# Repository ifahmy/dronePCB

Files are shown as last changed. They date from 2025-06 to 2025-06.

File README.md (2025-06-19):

# Tiny Drone Flight Controller PCB

This repository documents the design of a custom STM32-based nano drone flight controller, incorporating power management, 2.4 GHz radio, motion sensors, and brushed motor drivers. Designed for compatibility with **ArduPilot** and **Betaflight**.

---

## Microcontroller Unit (MCU)

- **STM32F722RET6**, selected for performance and documentation.
- 8 MHz HSE oscillator with tuning capacitors for STM32 and sensors.
- Power monitoring via voltage divider and ADC.
- On-board **SWDIO/SWCLK** for debugging and bootloader flashing (DFU mode via BOOT and RESET).
- **Decoupling capacitors** used throughout for stability under current spikes.

---

## MCU Pin Assignments

- Verified via STM32CubeIDE.
- PWM signals generated via hardware timers.
- Deconflicted JTAG and other peripheral capabilities.
- SPI used for IMU (vs I2C in Nano).
- Pin selections support both ArduPilot and Betaflight configurations.

---

## Sensors & Motor Drivers

- **IMU**: ICM-42688-P (connected via SPI3 for efficiency).
- **Barometer**: MS5611 (lower data rate, connected via I2C with pull-ups).
- **Motors**: Driven by SI2302 N-Channel MOSFETs (supports high-frequency PWM, no gate driver required).
- **Flyback protection**: SS14 Schottky diodes.
- **Gate protection**: 10Ω resistors to suppress transients.

---

## Power Regulation & Charging

- **Battery input** with reverse polarity protection.
- **MCP73831-2** for LiPo charging via USB (charge current ~40 mA with 24.9k resistor).
- **MCP1700** LDO regulator (2.8V output) for analog and digital circuits.
- **Ideal diode configuration** using PMOS + Schottky for automatic switching between USB and battery.

---

## 2.4 GHz Radio & USB Interface

- **nRF24L01+** radio connected to SPI1 with CE and CS via GPIO.
- External ¼-wave wire antenna (~1.25”) with matching network based on datasheet.
- **16 MHz oscillator** for the radio.
- **Micro-USB** interface with 27Ω series resistors.
- **PRTR5V0U2X** for USB ESD protection.

---

## PCB Design Overview

- 4-layer board:
  - Top and Bottom: Signal layers
  - Inner Layers: +2.8V and Ground
- Motor PWM routed in +2.8V layer due to limited space.

---

## Next Steps & Recommendations

- Order fabricated PCBs.
- Flash bootloader / firmware using DFU for Betaflight/ArduPilot.

### Future Improvements
- Migrate from 4-layer to 2-layer for cost/manufacturing optimization.
- Reroute motor gate PWM signals away from power planes if space allows.

---

## Bill of Materials (BOM)

For a full list, see the Bill of Materials Excel sheet. Sample entries:

| Ref | Description | Value | Manufacturer Part # | Digi-Key Part # |
|-----|---|---|---|---|
| U1  | IMU | ICM-42688-P | ICM-42688-P | 1428-ICM-42688-PTR-ND |
| U2  | Barometer | MS5611-01BA | MS561101BA03-50 | 223-1622-1-ND |
| U3  | RF Radio | nRF24L01+ | NRF24L01P-T | 4823-NRF24L01P-T-ND |

---

## Tools Used

- STM32CubeIDE (Pin config, firmware)
- KiCad 9.0  (PCB layout and schematic)
- DigiKey (Component sourcing)
- Calipers (Nano board dimensions)

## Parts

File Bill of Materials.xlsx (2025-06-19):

Item # | Reference | Qty | Description | Value | Footprint | Manufacturer PN | Digikey PN
1 | SW1 | 1 | SWITCH SLIDE SPDT 100MA 6V | SW_SPDT | Button_Switch_SMD:Nidec_Copal_CAS-120A | CAS-120A | CAS-120A-ND
2 | C9 | 1 | CAP CER 1000PF 25V X7R 0201 | 1n | Capacitor_SMD:C_0201_0603Metric | GRM033R71E102KA01D | 490-3184-1-ND
3 | C10,C12 | 2 | CAP CER 10000PF 25V X5R 0201 | 10n | Capacitor_SMD:C_0201_0603Metric | GRM033R61E103KA12D | 490-7194-1-ND
4 | C13,C39,C40,C41,C42,C45,C46 | 7 | CAP CER 0.1UF 6.3V X5R 0201 | 100n | Capacitor_SMD:C_0201_0603Metric | CL03A104KQ3NNNC | 1276-1013-1-ND
5 | C1,C2,C37 | 3 | CAP CER 4.7UF 6.3V X5R 0402 | 4.7u | Capacitor_SMD:C_0402_1005Metric | JMK105BBJ475MV-F | 587-2787-1-ND
6 | C3 | 1 | AP CER 1PF 50V C0G/NP0 0402 | 1p | Capacitor_SMD:C_0402_1005Metric | GJM1555C1H1R0BB01D | 490-6073-1-ND
7 | C4,C43 | 2 | CAP CER 0.1UF 10V X7R 0402 | 0.1u | Capacitor_SMD:C_0402_1005Metric | CL05B104KP5NNNC | 1276-1002-1-ND
8 | C5 | 1 | CAP CER 1.5PF 50V C0G/NP0 0402 | 1.5p | Capacitor_SMD:C_0402_1005Metric | 0402N1R5B500CT | 1292-1274-1-ND
9 | C6 | 1 | CAP CER 2200PF 50V X7R 0402 | 2.2n | Capacitor_SMD:C_0402_1005Metric | C0402C222J5RACTU | 399-C0402C222J5RACTUCT-ND
10 | C8 | 1 | CAP CER 4.7PF 50V C0G/NP0 0402 | 4.7p | Capacitor_SMD:C_0402_1005Metric | GRM1555C1H4R7CA01D | 490-5874-1-ND
11 | C11 | 1 | CAP CER 0.033UF 16V X7R 0402 | 33n | Capacitor_SMD:C_0402_1005Metric | GRM155R71C333KA01D | 490-3257-1-ND
12 | C14,C16 | 2 | CAP CER 22PF 50V C0G/NP0 0402 | 22p | Capacitor_SMD:C_0402_1005Metric | CL05C220JB51PNC | 1276-6849-1-ND
13 | C34,C35 | 2 | CAP CER 10PF 50V C0G/NPO 0402 | 10p | Capacitor_SMD:C_0402_1005Metric | CC0402JRNPO9BN100 | 311-1014-1-ND
14 | C38,C44 | 2 | CAP CER 1UF 6.3V X7R 0402 | 1u | Capacitor_SMD:C_0402_1005Metric | GRM155R70J105KA12D | 490-10024-1-ND
15 | C7,C17 | 2 | CAP CER 2.2UF 6.3V X7R 0603 | 2.2u | Capacitor_SMD:C_0603_1608Metric | CGA3E1X7R0J225K080AC | 445-6933-1-ND
16 | C36 | 1 | CAP CER 4.7UF 10V X5R 0603 | 4.7u | Capacitor_SMD:C_0603_1608Metric | CL10A475KP8NNNC | 1276-1044-1-ND
17 | C18 | 1 | CAP CER 10UF 10V X5R 0805 | 10u | Capacitor_SMD:C_0805_2012Metric | C0805C106K8PACTU | 399-C0805C106K8PACTUCT-ND
18 | C22 | 1 | CAP CER 22UF 6.3V X5R 0805 | 22u | Capacitor_SMD:C_0805_2012Metric | GRM21BR60J226ME39L | 490-1719-1-ND
19 | J11 | 1 | CONN RCPT USB2.0 MICRO B SMD R/A | USB_B_Micro | Connector_USB:USB_Micro-B_Amphenol_10104110_Horizontal | 10104110-0001LF | 609-4052-1-ND
20 | Y1 | 1 | CRYSTAL 16.000MHZ 22 PF SMD | 16Mhz | Crystal:Crystal_SMD_3225-4Pin_3.2x2.5mm | SXT32422AA48-16.000M | 2388-SXT32422AA48-16.000M-ND
21 | Y2 | 1 | CRYSTAL 8.0000MHZ 10PF SMD | 8Mhz | Crystal:Crystal_SMD_3225-4Pin_3.2x2.5mm | ECS-80-10-33-CGN-TR3 | 50-ECS-80-10-33-CGN-TR3CT-ND
22 | D1,D6,D7,D8 | 4 | DIODE SCHOTTKY 40V 1A DO214AC | SS14 | Diode_SMD:D_SMA | SS14 | 1655-SS14CT-ND
23 | D11 | 1 | TVS DIODE 5VWM 9.2VC DO219AB | SMF5V0A | Diode_SMD:D_SMF | SMF5V0A-M3-18 | 112-SMF5V0A-M3-18CT-ND
24 | D9 | 1 | DIODE SCHOTTKY 40V 5A PMDTM | RB088LAM-40TFR | Diode_SMD:D_SOD-123 | RB088LAM-40TFTR | 846-RB088LAM-40TFTRCT-ND
25 | U1 | 1 | MOTION SENSOR | ICM-42688-P | ICM_42688_P:PQFN50P300X250X97-14N | ICM-42688-P | 1428-ICM-42688-PTR-ND
26 | L1 | 1 | FIXED IND 3.9NH 750MA 0.14OHM SM | 3.9n | Inductor_SMD:L_0402_1005Metric | LQG15HS3N9B02D | 490-LQG15HS3N9B02DCT-ND
27 | L2 | 1 | FIXED IND 8.2NH 250MA 400MOHM SM | 8.2n | Inductor_SMD:L_0402_1005Metric | LRC0402CJ8N2GV001T | 712-LRC0402CJ8N2GV001TCT-ND
28 | L3 | 1 | FIXED IND 2.7NH 300MA 170MOHM SM | 2.7n | Inductor_SMD:L_0402_1005Metric | LRC0402CS2N7GV001T | 712-LRC0402CS2N7GV001TCT-ND
29 | D3,D4,D5,D10 | 4 | LED BLUE CLEAR 0402 SMD | LED | LED_SMD:LED_0402_1005Metric | 150040BS73240 | 732-11989-1-ND
30 | U3 | 1 | IC RF TXRX ISM>1GHZ 20QFN | nRF24L01P | Package_DFN_QFN:QFN-20-1EP_4x4mm_P0.5mm_EP2.5x2.5mm | NRF24L01P-T | 4823-NRF24L01P-T-ND
31 | U2 | 1 | SENSOR 17.4PSIA 24BIT | MS5611-01BA | Package_LGA:LGA-8_3x5mm_P1.25mm | MS561101BA03-50 | 223-1622-1-ND
32 | U8 | 1 | IC MCU 32BIT 512KB FLASH 64LQFP | STM32F722RET6 | Package_QFP:LQFP-64_10x10mm_P0.5mm | STM32F722RET6 | 497-17184-ND
33 | D2 | 1 | TVS DIODE 5.5VWM SOT143B | PRTR5V0U2X | Package_TO_SOT_SMD:SOT-143 | PRTR5V0U2X,215 | 1727-3884-1-ND
34 | Q1 | 1 | MOSFET P-CH 20V 4A SOT23-3 | DMG3415 | Package_TO_SOT_SMD:SOT-23 | DMG3415U-7 | DMG3415UDICT-ND
35 | U4 | 1 | IC REG LINEAR 2.8V 250MA SOT23-3 | MCP1700x-280xxTT | Package_TO_SOT_SMD:SOT-23 | MCP1700T-2802E/TT | MCP1700T-2802E/TTCT-ND
36 | U5 | 1 | IC BATT CNTL LI-ION 1CEL SOT23-5 | MCP73831-2-OT | Package_TO_SOT_SMD:SOT-23-5 | MCP73831T-2ACI/OT | MCP73831T-2ACI/OTCT-ND
37 | R1,R2,R3,R4,R24 | 5 | RES 10K OHM 1% 1/20W 0201 | 10k | Resistor_SMD:R_0201_0603Metric | RC0201FR-0710KL | 311-10.0KMCT-ND
38 | R5 | 1 | RES 24.9K OHM 1% 1/20W 0201 | 25k | Resistor_SMD:R_0201_0603Metric | RC0201FR-0724K9L | YAG2279CT-ND
39 | R6,R7 | 2 | RES 4.7K OHM 1% 1/20W 0201 | 4.7k | Resistor_SMD:R_0201_0603Metric | RMCF0201FT4K70 | RMCF0201FT4K70CT-ND
40 | R9 | 1 | RES 22K OHM 1% 1/20W 0201 | 22k | Resistor_SMD:R_0201_0603Metric | PFR03S-223-FNH | 2037-PFR03S-223-FNHCT-ND
41 | R10 | 1 | RES 1M OHM 5% 1/20W 0201 | 1M | Resistor_SMD:R_0201_0603Metric | WR02X105 JAL | 1292-WR02X105JALCT-ND
42 | R11,R12 | 2 | RES 27 OHM 5% 1/20W 0201 | 27 | Resistor_SMD:R_0201_0603Metric | RC0201JR-0727RL | YAG2291CT-ND
43 | R15,R16,R17,R18 | 4 | RES 10 OHM 1% 1/20W 0201 | 10 | Resistor_SMD:R_0201_0603Metric | RMCF0201FT10R0 | RMCF0201FT10R0CT-ND
44 | R25 | 1 | RES 1K OHM 1% 1/20W 0201 | 1k | Resistor_SMD:R_0201_0603Metric | RC0201FR-071KL | 311-1KMCT-ND
45 | R28 | 1 | RES SMD 100K OHM 0.5% 1/20W 0201 | 100K | Resistor_SMD:R_0201_0603Metric | ERJ-1RHD1003C | P15981CT-ND
46 | R8 | 1 | RES 470 OHM 1% 1/16W 0402 | 470 | Resistor_SMD:R_0402_1005Metric | RC0402FR-07470RL | 311-470LRCT-ND
47 | R13,R14,R29 | 3 | RES 330 OHM 1% 1/10W 0402 | 330 | Resistor_SMD:R_0402_1005Metric | RK73H1ETTP3300F | 2019-RK73H1ETTP3300FCT-ND
48 | R23 | 1 | RES SMD 0 OHM JUMPER 1/16W | 0R | Resistor_SMD:R_0402_1005Metric | RC1005J000CS | 1276-3480-1-ND
49 | R26 | 1 | RES 10K OHM 5% 1/16W 0402 | 10k | Resistor_SMD:R_0402_1005Metric | RC0402JR-0710KL | 311-10KJRCT-ND
50 | FB1 | 1 | FERRITE BEAD 120 OHM 0603 1LN | 120R @ 100MHz | Resistor_SMD:R_0603_1608Metric | MMZ1608S121ATA00 | 445-MMZ1608S121ATA00CT-ND
51 | MOSFET1,MOSFET2,MOSFET3,MOSFET4 | 4 | MOSFET N-CH 20V 3A SOT-23 | SI2302-TP | SOT-23_MCC | SI2302-TP | SI2302-TPMSCT-ND

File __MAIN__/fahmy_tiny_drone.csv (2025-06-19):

Reference | Qty | Value | Footprint
C1,C2,C37 | 3 | 4.7u | Capacitor_SMD:C_0402_1005Metric
C3 | 1 | 1p | Capacitor_SMD:C_0402_1005Metric
C4,C43 | 2 | 0.1u | Capacitor_SMD:C_0402_1005Metric
C5 | 1 | 1.5p | Capacitor_SMD:C_0402_1005Metric
C6 | 1 | 2.2n | Capacitor_SMD:C_0402_1005Metric
C7,C17 | 2 | 2.2u | Capacitor_SMD:C_0603_1608Metric
C8 | 1 | 4.7p | Capacitor_SMD:C_0402_1005Metric
C9 | 1 | 1n | Capacitor_SMD:C_0201_0603Metric
C10,C12 | 2 | 10n | Capacitor_SMD:C_0201_0603Metric
C11 | 1 | 33n | Capacitor_SMD:C_0402_1005Metric
C13,C39,C40,C41,C42,C45,C46 | 7 | 100n | Capacitor_SMD:C_0201_0603Metric
C14,C16 | 2 | 22p | Capacitor_SMD:C_0402_1005Metric
C18 | 1 | 10u | Capacitor_SMD:C_0805_2012Metric
C22 | 1 | 22u | Capacitor_SMD:C_0805_2012Metric
C34,C35 | 2 | 10p | Capacitor_SMD:C_0402_1005Metric
C36 | 1 | 4.7u | Capacitor_SMD:C_0603_1608Metric
C38,C44 | 2 | 1u | Capacitor_SMD:C_0402_1005Metric
D1,D6,D7,D8 | 4 | SS14 | Diode_SMD:D_SMA
D2 | 1 | PRTR5V0U2X | Package_TO_SOT_SMD:SOT-143
D3,D4,D5,D10 | 4 | LED | LED_SMD:LED_0402_1005Metric
D9 | 1 | RB088LAM-40TFR | Diode_SMD:D_SOD-123
D11 | 1 | SMF5V0A | Diode_SMD:D_SMF
FB1 | 1 | 120R @ 100KHz | Resistor_SMD:R_0603_1608Metric
J1 | 1 | M1+ | TestPoint:TestPoint_Pad_D1.0mm
J2 | 1 | M1- | TestPoint:TestPoint_Pad_D1.0mm
J3 | 1 | M2+ | TestPoint:TestPoint_Pad_D1.0mm
J4 | 1 | M2- | TestPoint:TestPoint_Pad_D1.0mm
J5 | 1 | M3+ | TestPoint:TestPoint_Pad_D1.0mm
J6 | 1 | M3- | TestPoint:TestPoint_Pad_D1.0mm
J7 | 1 | M4+ | TestPoint:TestPoint_Pad_D1.0mm
J8 | 1 | M4- | TestPoint:TestPoint_Pad_D1.0mm
J9 | 1 | #NAME? | TestPoint:TestPoint_Pad_D1.0mm
J10 | 1 | GND | TestPoint:TestPoint_Pad_D1.0mm
J11 | 1 | USB_B_Micro | Connector_USB:USB_Micro-B_Amphenol_10104110_Horizontal
J12 | 1 | ANT | TestPoint:TestPoint_Pad_D1.0mm
J13 | 1 | SWDIO | TestPoint:TestPoint_Pad_D1.0mm
J14 | 1 | SWCLK | TestPoint:TestPoint_Pad_D1.0mm
JP1 | 1 | NRST | Jumper:SolderJumper-2_P1.3mm_Open_TrianglePad1.0x1.5mm
L1 | 1 | 3.9n | Inductor_SMD:L_0402_1005Metric
L2 | 1 | 8.2n | Inductor_SMD:L_0402_1005Metric
L3 | 1 | 2.7n | Inductor_SMD:L_0402_1005Metric
MOSFET1,MOSFET2,MOSFET3,MOSFET4 | 4 | SI2302-TP | SOT-23_MCC
Q1 | 1 | DMG3415 | Package_TO_SOT_SMD:SOT-23
R1,R2,R3,R4,R24 | 5 | 10k | Resistor_SMD:R_0201_0603Metric
R5 | 1 | 25k | Resistor_SMD:R_0201_0603Metric
R6,R7 | 2 | 4.7k | Resistor_SMD:R_0201_0603Metric
R8 | 1 | 470 | Resistor_SMD:R_0402_1005Metric
R9 | 1 | 22k | Resistor_SMD:R_0201_0603Metric
R10 | 1 | 1M | Resistor_SMD:R_0201_0603Metric
R11,R12 | 2 | 27 | Resistor_SMD:R_0201_0603Metric
R13,R14,R29 | 3 | 330 | Resistor_SMD:R_0402_1005Metric
R15,R16,R17,R18 | 4 | 10 | Resistor_SMD:R_0201_0603Metric
R23 | 1 | 0R | Resistor_SMD:R_0402_1005Metric
R25 | 1 | 1k | Resistor_SMD:R_0201_0603Metric
R26 | 1 | 10k | Resistor_SMD:R_0402_1005Metric
R28 | 1 | 100K | Resistor_SMD:R_0201_0603Metric
SW1 | 1 | SW_SPDT | Button_Switch_SMD:Nidec_Copal_CAS-120A
U1 | 1 | ICM-42688-P | ICM_42688_P:PQFN50P300X250X97-14N
U2 | 1 | MS5611-01BA | Package_LGA:LGA-8_3x5mm_P1.25mm
U3 | 1 | nRF24L01P | Package_DFN_QFN:QFN-20-1EP_4x4mm_P0.5mm_EP2.5x2.5mm
U4 | 1 | MCP1700x-280xxTT | Package_TO_SOT_SMD:SOT-23
U5 | 1 | MCP73831-2-OT | Package_TO_SOT_SMD:SOT-23-5
U8 | 1 | STM32F722RET6 | Package_QFP:LQFP-64_10x10mm_P0.5mm
Y1 | 1 | 16Mhz | Crystal:Crystal_SMD_3225-4Pin_3.2x2.5mm
Y2 | 1 | 8Mhz | Crystal:Crystal_SMD_3225-4Pin_3.2x2.5mm

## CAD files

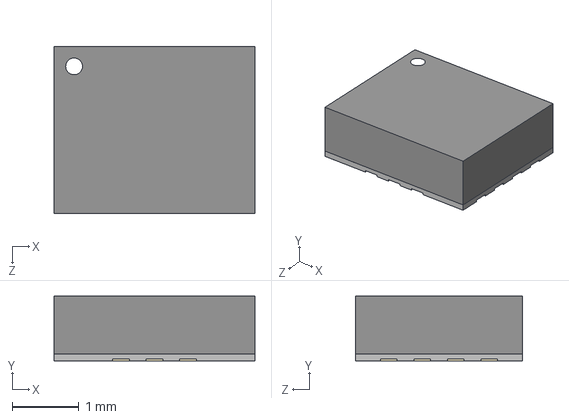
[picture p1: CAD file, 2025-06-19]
__MAIN__/Parts/ICM_42688_P/ICM-42688-P.step
3.00 x 0.97 x 2.50 mm

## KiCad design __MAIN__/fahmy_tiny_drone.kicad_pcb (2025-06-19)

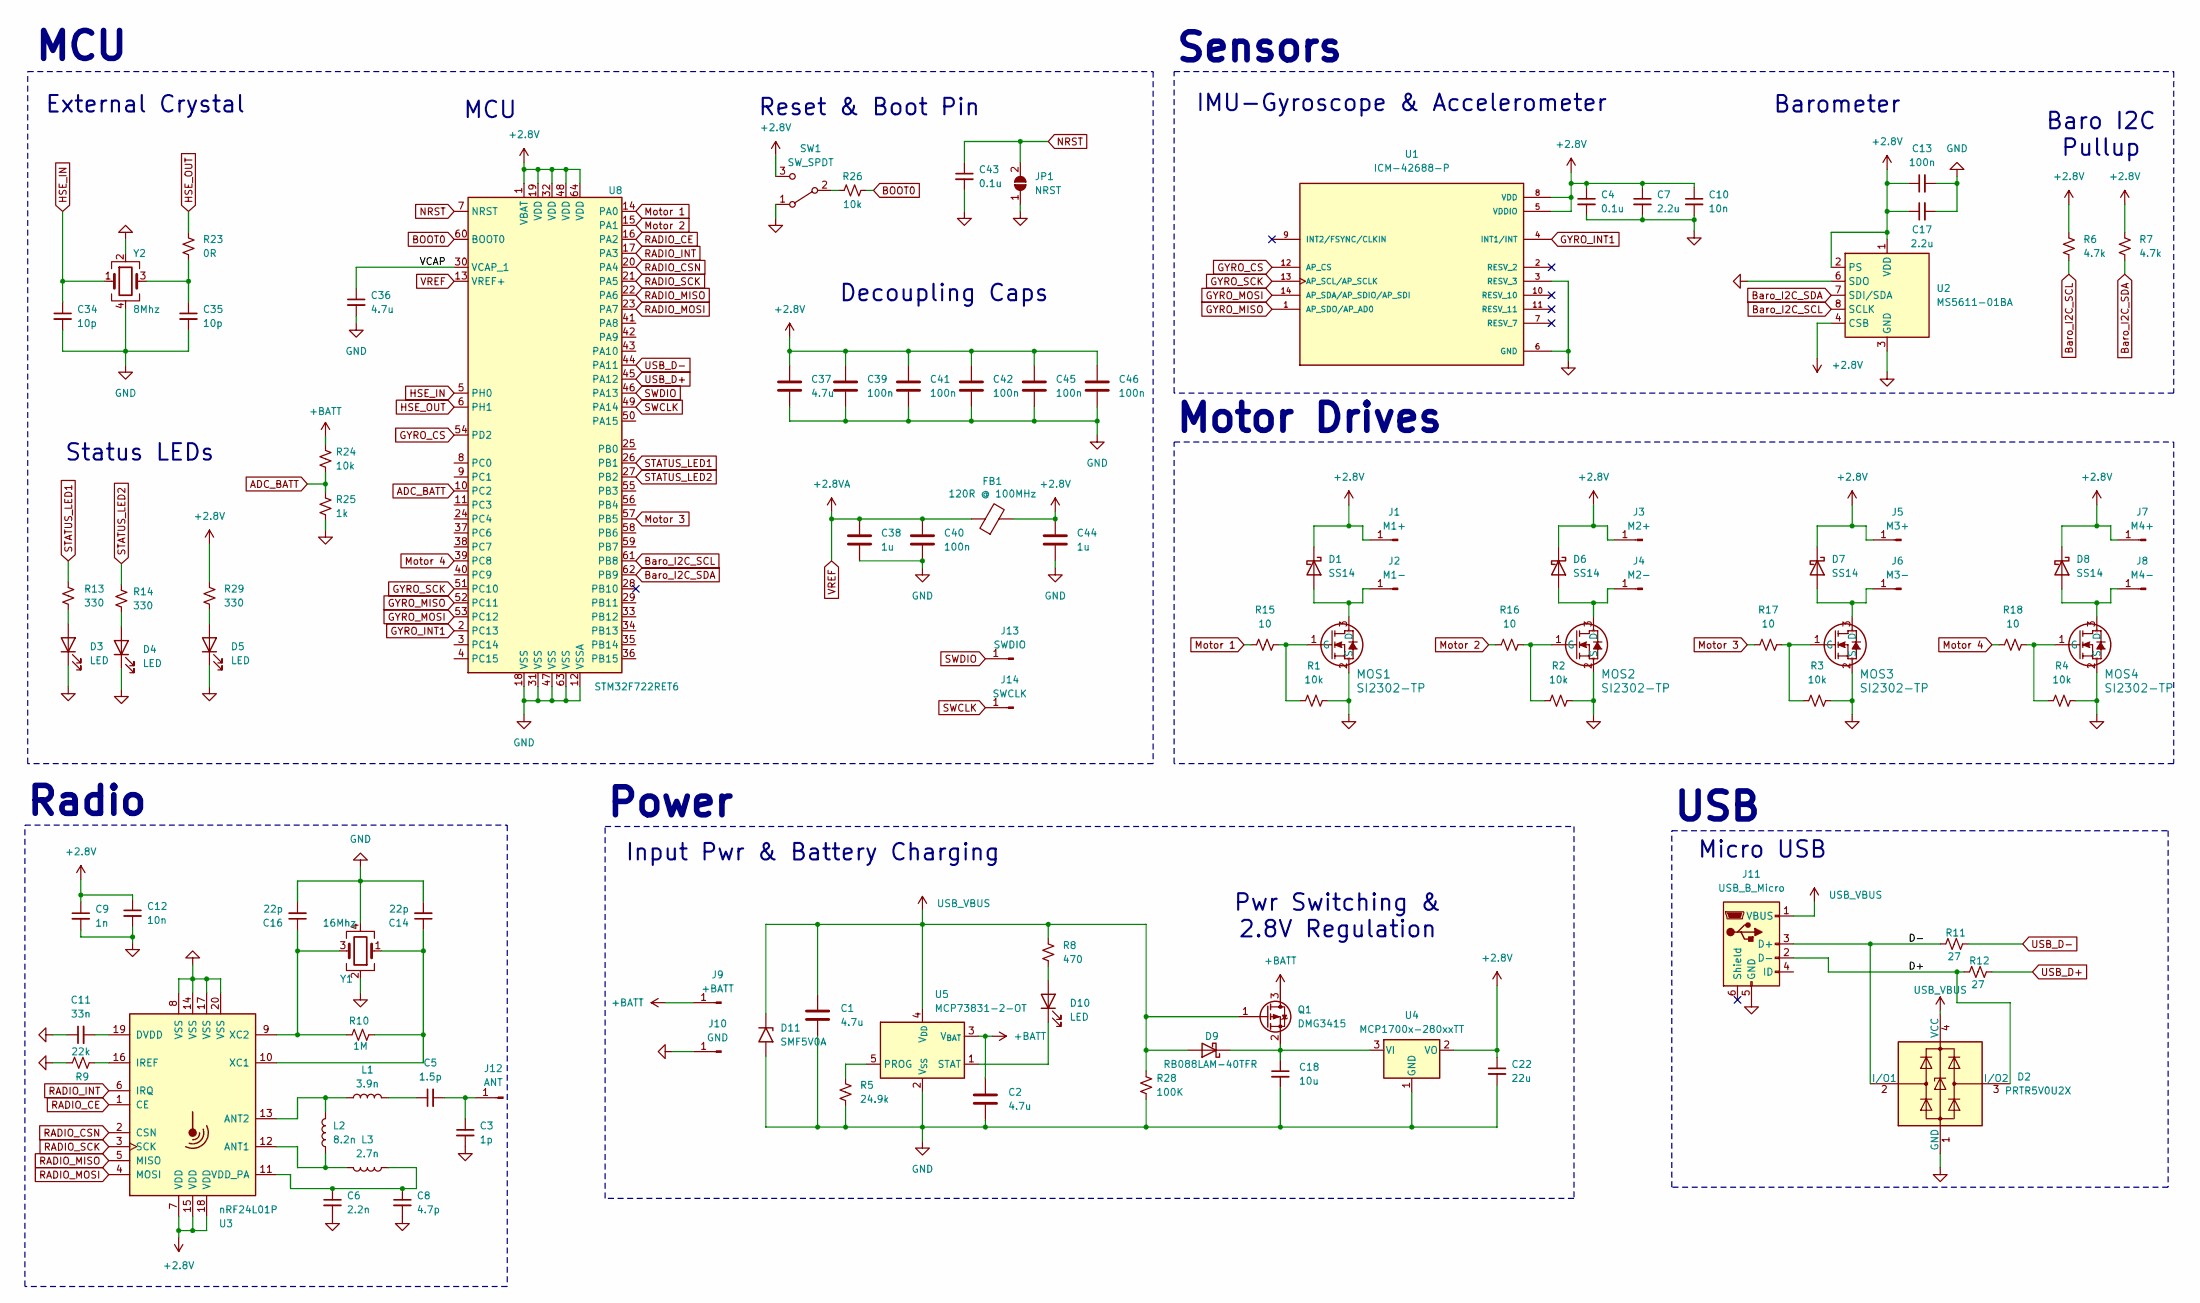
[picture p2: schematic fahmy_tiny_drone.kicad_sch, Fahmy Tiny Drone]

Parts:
C1, C2, C37: 4.7u; C_0402_1005Metric
C3: 1p; C_0402_1005Metric
C4, C43: 0.1u; C_0402_1005Metric
C5: 1.5p; C_0402_1005Metric
C6: 2.2n; C_0402_1005Metric
C7, C17: 2.2u; C_0603_1608Metric
C8: 4.7p; C_0402_1005Metric
C9: 1n; C_0201_0603Metric
C10, C12: 10n; C_0201_0603Metric
C11: 33n; C_0402_1005Metric
C13, C39, C40, C41, C42, C45, C46: 100n; C_0201_0603Metric
C14, C16: 22p; C_0402_1005Metric
C18: 10u; C_0805_2012Metric
C22: 22u; C_0805_2012Metric
C34, C35: 10p; C_0402_1005Metric
C36: 4.7u; C_0603_1608Metric
C38, C44: 1u; C_0402_1005Metric
D1, D6, D7, D8: SS14; D_SMA
D2: PRTR5V0U2X; SOT-143
D3, D4, D5, D10: LED; LED_0402_1005Metric
D9: RB088LAM-40TFR; D_SOD-123
D11: SMF5V0A; D_SMF
FB1: 120R @ 100MHz; R_0603_1608Metric
J1: M1+; TestPoint_Pad_D1.0mm
J2: M1-; TestPoint_Pad_D1.0mm
J3: M2+; TestPoint_Pad_D1.0mm
J4: M2-; TestPoint_Pad_D1.0mm
J5: M3+; TestPoint_Pad_D1.0mm
J6: M3-; TestPoint_Pad_D1.0mm
J7: M4+; TestPoint_Pad_D1.0mm
J8: M4-; TestPoint_Pad_D1.0mm
J9: +BATT; TestPoint_Pad_D1.0mm
J10: GND; TestPoint_Pad_D1.0mm
J11: USB_B_Micro; USB_Micro-B_Amphenol_10104110_Horizontal
J12: ANT; TestPoint_Pad_D1.0mm
J13: SWDIO; TestPoint_Pad_D1.0mm
J14: SWCLK; TestPoint_Pad_D1.0mm
JP1: NRST; SolderJumper-2_P1.3mm_Open_TrianglePad1.0x1.5mm
L1: 3.9n; L_0402_1005Metric
L2: 8.2n; L_0402_1005Metric
L3: 2.7n; L_0402_1005Metric
MOS1, MOS2, MOS3, MOS4: SI2302-TP; SOT-23_MCC
Q1: DMG3415; SOT-23
R1, R2, R3, R4, R24: 10k; R_0201_0603Metric
R5: 24.9k; R_0201_0603Metric
R6, R7: 4.7k; R_0201_0603Metric
R8: 470; R_0402_1005Metric
R9: 22k; R_0201_0603Metric
R10: 1M; R_0201_0603Metric
R11, R12: 27; R_0201_0603Metric
R13, R14, R29: 330; R_0402_1005Metric
R15, R16, R17, R18: 10; R_0201_0603Metric
R23: 0R; R_0402_1005Metric
R25: 1k; R_0201_0603Metric
R26: 10k; R_0402_1005Metric
R28: 100K; R_0201_0603Metric
SW1: SW_SPDT; Nidec_Copal_CAS-120A
U1: ICM-42688-P; PQFN50P300X250X97-14N; PARTREV 1.2
U2: MS5611-01BA; LGA-8_3x5mm_P1.25mm
U3: nRF24L01P; QFN-20-1EP_4x4mm_P0.5mm_EP2.5x2.5mm
U4: MCP1700x-280xxTT; SOT-23
U5: MCP73831-2-OT; SOT-23-5
U8: STM32F722RET6; LQFP-64_10x10mm_P0.5mm
Y1: 16Mhz; Crystal_SMD_3225-4Pin_3.2x2.5mm
Y2: 8Mhz; Crystal_SMD_3225-4Pin_3.2x2.5mm

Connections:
+2.8V: C4.1, C7.1, C9.1, C10.1, C12.1, C13.1, C17.1, C22.1, C37.1, C39.1, C41.1, C42.1, C44.1, C45.1, C46.1, D1.1 (K), D6.1 (K), D7.1 (K), D8.1 (K), FB1.2, J1.1, J3.1, J5.1, J7.1, R6.1, R7.1, R29.1, SW1.3 (C), U1.5 (VDDIO), U1.8 (VDD), U2.1 (VDD), U2.2 (PS), U2.4 (CSB), U2.5 (CSB), U3.7 (VDD), U3.15 (VDD), U3.18 (VDD), U4.2 (VO), U8.1 (VBAT), U8.19 (VDD), U8.32 (VDD), U8.48 (VDD), U8.64 (VDD)
+BATT: C2.1, J9.1, Q1.3 (D), R24.1, U5.3 (V_{BAT})
/D+: D2.3 (I/O2), J11.2 (D-), R12.1
/D-: D2.2 (I/O1), J11.3 (D+), R11.1
/VCAP: C36.1, U8.30 (VCAP_1)
ADC_BATT: R24.2, R25.1, U8.10 (PC2)
BOOT0: R26.2, U8.60 (BOOT0)
Baro_I2C_SCL: R6.2, U2.8 (SCLK), U8.61 (PB8)
Baro_I2C_SDA: R7.2, U2.7 (SDI/SDA), U8.62 (PB9)
GND: C1.2, C2.2, C3.2, C4.2, C6.2, C7.2, C8.2, C9.2, C10.2, C11.1, C12.2, C13.2, C14.2, C16.2, C17.2, C18.2, C22.2, C34.2, C35.2, C36.2, C37.2, C38.2, C39.2, C40.2, C41.2, C42.2, C43.2, C44.2, C45.2, C46.2, D2.1 (GND), D3.1 (K), D4.1 (K), D5.1 (K), D11.2 (A2), J10.1, J11.5 (GND), JP1.1 (A), MOS1.2 (S), MOS2.2 (S), MOS3.2 (S), MOS4.2 (S), R1.2, R2.2, R3.2, R4.2, R5.2, R9.1, R25.2, R28.2, SW1.1 (A), U1.3 (RESV_3), U1.6 (GND), U2.3 (GND), U2.6 (SDO), U3.8 (VSS), U3.14 (VSS), U3.17 (VSS), U3.20 (VSS), U4.1 (GND), U5.2 (V_{SS}), U8.12 (VSSA), U8.18 (VSS), U8.31 (VSS), U8.47 (VSS), U8.63 (VSS), Y1.2, Y1.4, Y2.2, Y2.4
GYRO_CS: U1.12 (AP_CS), U8.54 (PD2)
GYRO_INT1: U1.4 (INT1/INT), U8.2 (PC13)
GYRO_MISO: U1.1 (AP_SDO/AP_AD0), U8.52 (PC11)
GYRO_MOSI: U1.14 (AP_SDA/AP_SDIO/AP_SDI), U8.53 (PC12)
GYRO_SCK: U1.13 (AP_SCL/AP_SCLK), U8.51 (PC10)
HSE_IN: C34.1, U8.5 (PH0), Y2.1
HSE_OUT: R23.1, U8.6 (PH1)
Motor 1: R15.1, U8.14 (PA0)
Motor 2: R16.1, U8.15 (PA1)
Motor 3: R17.1, U8.57 (PB5)
Motor 4: R18.1, U8.39 (PC8)
NRST: C43.1, JP1.2 (B), U8.7 (NRST)
unnamed: C5.1, L1.2
unnamed: C35.1, R23.2, Y2.3
unnamed: D1.2 (A), J2.1, MOS1.3 (D)
unnamed: D3.2 (A), R13.2
unnamed: D4.2 (A), R14.2
unnamed: D5.2 (A), R29.2
unnamed: D6.2 (A), J4.1, MOS2.3 (D)
unnamed: D7.2 (A), J6.1, MOS3.3 (D)
unnamed: D8.2 (A), J8.1, MOS4.3 (D)
unnamed: C18.1, D9.1 (K), Q1.2 (S), U4.3 (VI)
unnamed: D10.2 (A), R8.2
unnamed: D10.1 (K), U5.1 (STAT)
unnamed: C3.1, C5.2, J12.1
unnamed: MOS1.1 (G), R1.1, R15.2
unnamed: MOS2.1 (G), R2.1, R16.2
unnamed: MOS3.1 (G), R3.1, R17.2
unnamed: MOS4.1 (G), R4.1, R18.2
unnamed: R26.1, SW1.2 (B)
unnamed: L2.1, L3.2, U3.12 (ANT1)
unnamed: L1.1, L2.2, U3.13 (ANT2)
unnamed: C11.2, U3.19 (DVDD)
unnamed: R9.2, U3.16 (IREF)
unnamed: C6.1, C8.1, L3.1, U3.11 (VDD_PA)
unnamed: C14.1, R10.1, U3.10 (XC1), Y1.1
unnamed: C16.1, R10.2, U3.9 (XC2), Y1.3
unnamed: R5.1, U5.5 (PROG)
RADIO_CE: U3.1 (CE), U8.16 (PA2)
RADIO_CSN: U3.2 (CSN), U8.20 (PA4)
RADIO_INT: U3.6 (IRQ), U8.17 (PA3)
RADIO_MISO: U3.5 (MISO), U8.22 (PA6)
RADIO_MOSI: U3.4 (MOSI), U8.23 (PA7)
RADIO_SCK: U3.3 (SCK), U8.21 (PA5)
STATUS_LED1: R13.1, U8.26 (PB1)
STATUS_LED2: R14.1, U8.27 (PB2)
SWCLK: J14.1, U8.49 (PA14)
SWDIO: J13.1, U8.46 (PA13)
USB_D+: R12.2, U8.45 (PA12)
USB_D-: R11.2, U8.44 (PA11)
USB_VBUS: C1.1, D2.4 (VCC), D9.2 (A), D11.1 (A1), J11.1 (VBUS), Q1.1 (G), R8.1, R28.1, U5.4 (V_{DD})
VREF: C38.1, C40.1, FB1.1, U8.13 (VREF+)

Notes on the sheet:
Motor Drives
Radio
Baro I2C Pullup
Status LEDs
MCU
Pwr Switching & 2.8V Regulation
Decoupling Caps
Barometer
Reset & Boot Pin
Power
USB
External Crystal
Sensors
Micro USB
Input Pwr & Battery Charging
IMU-Gyroscope & Accelerometer

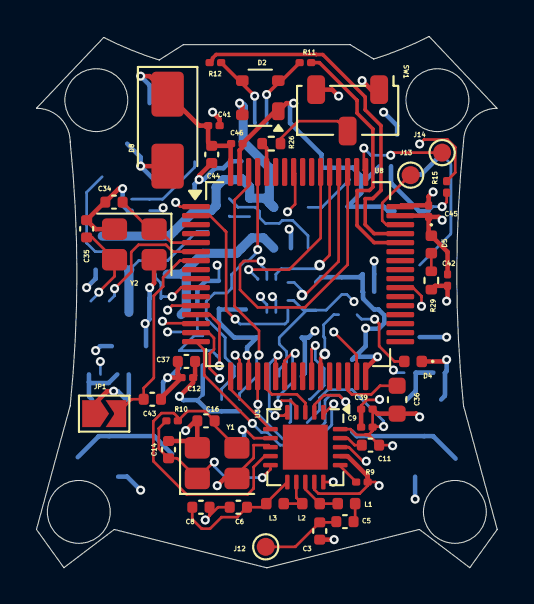
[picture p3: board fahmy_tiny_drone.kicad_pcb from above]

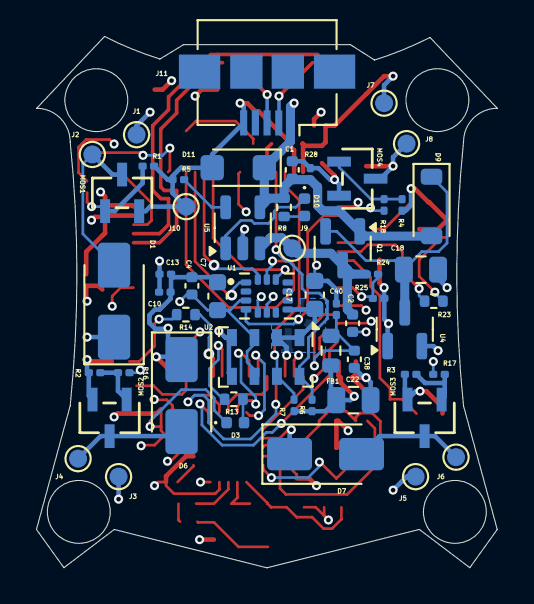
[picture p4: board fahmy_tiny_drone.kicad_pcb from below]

Board: 4 copper layers, 25.6 x 29.5 mm, 99 parts (56 on the bottom side), 62 nets.

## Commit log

2025-06-19 Initial upload of PCB Layout
    [ICM-42688-P.step, fahmy_tiny_drone.csv, fahmy_tiny_drone.kicad_pcb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]
2025-06-19 Added BOM
    [Bill of Materials.xlsx]
